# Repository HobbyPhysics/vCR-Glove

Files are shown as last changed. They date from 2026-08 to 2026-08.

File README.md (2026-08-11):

# vCR-Glove
Open-source vibrotactile coordinated reset glove hardware, firmware, and fabrication files

## License

The hardware design files in the `PCB/` and `3D_Printing/` directories are licensed under the CERN Open Hardware Licence Version 2 - Permissive (CERN-OHL-P-2.0). See `LICENSE-HARDWARE.txt`.

The firmware in the `Firmware/` directory is licensed under the MIT License. See `Firmware/LICENSE.txt`.

These licenses permit commercial use of the designs and firmware subject to the terms of the respective licenses. No warranty is provided.

## Project Status

This project is under active development. Design files and documentation may be updated as testing progresses.

## Construction and Technical Experience

This project requires experience with electronic assembly, soldering, PCB fabrication and assembly services, microcontroller programming, and mechanical fabrication.

The documentation and design files are provided to allow technically experienced users to reproduce or modify the project. They are not intended to provide comprehensive instruction in the underlying fabrication and assembly techniques.

Users who do not have experience with these techniques are encouraged to obtain assistance from someone familiar with electronic assembly and fabrication.

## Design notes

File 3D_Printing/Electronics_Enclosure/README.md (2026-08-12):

# Electronics Enclosure

This directory contains the source and fabrication files for the vCR Glove electronics enclosure.

The enclosure houses the printed circuit board, battery, controls, connectors, and related wiring.

## Directory Contents

- `OpenSCAD_Source/` - editable parametric OpenSCAD source files
- `STL/` - rendered STL files for fabrication

See the README files within these directories for additional information.

## Manufacturing

The enclosure parts used in the project were manufactured by JLC3DP using:

- **Process:** SLA
- **Material:** Black resin
- **Supplier:** JLC3DP

The STL files in this repository correspond to the current OpenSCAD source files.

Because SLA dimensions, shrinkage, and warping can vary with resin and process, users employing a different material or manufacturing method should review critical dimensions before fabrication.

## License

These mechanical design files are licensed under CERN-OHL-P-2.0. See `LICENSE-HARDWARE.txt` in the repository root.

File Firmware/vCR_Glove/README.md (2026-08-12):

# vCR Glove Firmware

This directory contains the Arduino firmware for the two vCR Glove electronic units.

The same firmware is used for both the left-hand and right-hand units. A setting near the beginning of the program (IS_LEFT_HAND) identifies which hand is being programmed.

## Requirements

The firmware is intended for the:

- Seeed Studio XIAO nRF52840
- Arduino IDE
- vCR Glove PCB and electronics described in this repository

Install the Arduino IDE and the required board support and libraries before compiling the program.

## Opening the Firmware

Open:

`vCR_Glove.ino`

in the Arduino IDE.

The Arduino IDE should recognize the file as the `vCR_Glove` sketch.

## Selecting the Hand

Before uploading the firmware, locate the following setting near the beginning of the program:

`IS_LEFT_HAND`

Set this value appropriately for the unit being programmed:

- `IS_LEFT_HAND = 1` - left-hand unit
- `IS_LEFT_HAND = 0` - right-hand unit

Both units use otherwise identical firmware.

## Programming the First Unit

1. Turn the vCR Glove unit power switch **OFF**.
2. Connect the unit to the computer using a USB cable.
3. Start the Arduino IDE and open `vCR_Glove.ino`.
4. Set `IS_LEFT_HAND` for the hand being programmed.
5. Select the **Seeed Studio XIAO nRF52840** as the target board.
6. Select the COM port assigned to the connected XIAO.
7. Verify/compile the program.
8. Upload the firmware to the unit.

After a successful upload, disconnect the USB cable.

## Programming the Second Unit

1. Connect the second hand unit to the computer by USB with its power switch **OFF**.
2. Change `IS_LEFT_HAND` to the setting for the second hand.
3. Select the COM port assigned to the second XIAO.
4. Verify/compile the program.
5. Upload the firmware.
6. Disconnect the USB cable.

Both units are now programmed with the same firmware but with their respective left/right hand identifiers.

## Operation

With both units programmed and disconnected from USB:

1. Turn on both units.
2. Press the START button on either unit.
3. The two units establish Bluetooth communication and begin the synchronized stimulation sequence after a short delay.

Only one START button needs to be pressed.

Turning the units off stops operation. After power is restored, stimulation does not begin until a START button is pressed.

## Source Code

Operating parameters and hardware assignments are defined in the Arduino source code. These include the actuator drive parameters, burst timing, channel sequencing, amplitude control, indicator LEDs, amplifier control, and Bluetooth synchronization.

The firmware supplied here corresponds to the vCR Glove hardware documented in this repository.

## Arduino IDE Configuration

The firmware was compiled and tested using the following Arduino board configuration:

* **Board:** Seeed XIAO nRF52840 Sense
* **Board support package:** Seeed nRF52 Boards
* **Tested version:** 1.1.13

Install the `Seeed nRF52 Boards` package using the Arduino IDE Boards Manager and select **Seeed XIAO nRF52840 Sense** as the target board.

The firmware uses:

`#include <bluefruit.h>`

`#include <math.h>`

`#include <nrf.h>`

No separately installed Arduino libraries are required for these includes. In particular, the Bluefruit support used by this firmware is supplied by the `Seeed nRF52 Boards` package.

The similarly named **Seeed nRF52 mbed-enabled Boards** package should not be substituted for the board package specified above.

## Single-frequency mode:

250 Hz on all channels. Closest to the published Tass-style stimulation.

## Multi-frequency mode:
Experimental option using 207.65, 233.08, 277.18, and 311.13 Hz.
Finger order and frequency order are independently shuffled each CR cycle.
This mode has not been evaluated clinically and is not part of the published Tass protocol.

## License

The firmware is licensed under the MIT License. See:

`../LICENSE.txt`

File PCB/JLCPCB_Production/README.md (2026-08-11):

# JLCPCB Production Files

This directory contains the production files used to manufacture and assemble the vCR Glove printed circuit board using JLCPCB.

These files were generated from the KiCad design contained in the adjacent `KiCad_Source` directory.

Detailed ordering instructions are provided in the vCR Glove Project articles on the Hobby Physics blog. The notes below identify several issues that may be encountered when using the JLCPCB ordering system.

## PCB Fabrication

The ZIP file contains the Gerber and drill files required to manufacture the bare PCB.

Upload the ZIP file directly to the JLCPCB PCB ordering system. It is not necessary to extract the individual Gerber and drill files before uploading.

## PCB Assembly

The two CSV files are used for JLCPCB PCB assembly:

- **BOM (Bill of Materials)** - identifies the components and their reference designators.
- **Top Position / Pick-and-Place file** - specifies the location and orientation of the components installed on the top side of the PCB.

These files are uploaded during the PCB assembly portion of the JLCPCB ordering process.

## Important Assembly Checks

The JLCPCB assembly configuration and component placement should be carefully reviewed before placing an order. The production files provide the design information, but some selections and corrections may be required in the JLCPCB ordering interface.

### Component Availability

JLCPCB/LCSC component availability, pricing, and minimum order quantities can change.

A component specified in the BOM may become unavailable or may require a different minimum quantity. The JLCPCB system may report an error or suggest substitute components.

Any substitute should be checked for electrical specifications, package, footprint, and pinout before accepting it.

### DNP Components

Some components in the KiCad schematic are designated **DNP (Do Not Populate)** and are marked with a red X.

These components are intentionally not installed. JLCPCB may display warnings or comments associated with these unpopulated locations. These should not be interpreted as missing components that must necessarily be added.

The intended populated configuration should be compared with the schematic before responding to DNP-related warnings.

### Component Orientation and Position

Do not assume that all components shown in the JLCPCB assembly viewer have the correct orientation or exact position.

Differences between the KiCad placement data and the JLCPCB assembly system can result in some components appearing rotated or displaced in the JLCPCB viewer.

In the board used for this project, particular attention should be paid to:

- **JST connectors** - some may require rotation by 90 or 180 degrees and adjustment of their position so that they align correctly with the PCB through holes.
- **Electrolytic capacitor** - the capacitor may require a 180-degree rotation and position adjustment. Polarity must be checked carefully.

The JLCPCB assembly editing tools can be used during the ordering process to correct component rotation and position.

## Before Ordering

Before approving PCB assembly:

1. Review all BOM component selections and resolve unavailable components carefully.
2. Confirm that DNP components remain unpopulated.
3. Inspect the orientation and position of every component in the JLCPCB assembly viewer.
4. Pay particular attention to connectors and polarized components.
5. Compare the JLCPCB assembly preview with the KiCad PCB layout, schematic, and 3D view.

Do not approve the assembly solely because the BOM and placement files were accepted without errors.

## Design Version

These production files correspond to the PCB version documented in this repository. JLCPCB component inventory and its ordering interface may change over time.

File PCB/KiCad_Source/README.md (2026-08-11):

# KiCad Source Files
# KiCad Source Files

This directory contains the editable KiCad source files for the vCR Glove printed circuit board.

The project was created using KiCad. To open the complete project, start KiCad and open the `.kicad_pro` project file. The schematic and PCB layout can then be opened from the KiCad Project Manager.

## Files

- `.kicad_pro` - KiCad project file
- `.kicad_sch` - schematics
- `.kicad_pcb` - PCB layout

## Schematic DNP Markings

Some components in the schematic are marked with a red X. These components have been designated **DNP (Do Not Populate)** in KiCad.

The components are intentionally retained in the schematic but are not installed on the manufactured PCB. The red X is therefore not an error indication. It provides a visual record of optional or unused components and identifies the configuration used for production.

## Viewing the PCB

Open the `.kicad_pcb` file from the KiCad Project Manager to view the PCB layout.

KiCad can also display a three-dimensional representation of the assembled PCB. With the PCB Editor open, select:

**View → 3D Viewer**

The 3D Viewer can be rotated and zoomed to inspect the component placement and overall board assembly.

## Manufacturing Files

The files used to order the PCB and assembled board are provided separately in:

`../JLCPCB_Production/`

Those production files should be used for reproducing the manufactured board. The files in this directory are provided for viewing or modifying the design.

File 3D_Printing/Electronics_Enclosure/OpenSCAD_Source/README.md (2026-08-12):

# Electronics Enclosure OpenSCAD Source

This directory contains the editable OpenSCAD source file for the vCR Glove electronics enclosure.

A single OpenSCAD file defines both printable components of the enclosure and also provides assembled and exploded views for inspection.

## Selecting the Output

The variable `output_part` near the beginning of the OpenSCAD file selects what is displayed:

- `output_part = "box";` - enclosure bottom
- `output_part = "top";` - enclosure top (lid)
- `output_part = "assembly";` - assembled view for inspection
- `output_part = "exploded";` - exploded view for inspection

The `assembly` and `exploded` options are provided for visualization and are not intended to generate manufacturing STL files.

## Generating the STL Files

Two STL files are required for fabrication.

### Enclosure Bottom

Set:

`output_part = "box";`

Press **F6** to render the model, inspect it, and then select:

**File → Export → Export as STL**

Save the result using the `_bottom.stl` filename.

### Enclosure Top

Set:

`output_part = "top";`

Press **F6** to render the model, inspect it, and then select:

**File → Export → Export as STL**

Save the result using the `_top.stl` filename.

The resulting STL files are provided in:

`../STL/`

## Viewing the Complete Enclosure

For an assembled view, set:

`output_part = "assembly";`

For a separated view showing the relationship between the components, set:

`output_part = "exploded";`

These modes are useful for inspecting the enclosure design without generating separate manufacturing parts.

## Parametric Design

The enclosure is designed parametrically. Important dimensions are defined near the beginning of the OpenSCAD source file.

If dimensions are changed, both the top and bottom should be reviewed and new STL files generated as necessary.

## Manufacturing

The enclosure used in the project was manufactured by JLC3DP using:

- **Process:** SLA
- **Material:** Black resin

Manufacturing tolerances, shrinkage, and warping can vary with material and process. Critical dimensions should therefore be reviewed if a different manufacturing process or material is used.

## License

The OpenSCAD source file is a hardware design file licensed under CERN-OHL-P-2.0. See `LICENSE-HARDWARE.txt` in the repository root.

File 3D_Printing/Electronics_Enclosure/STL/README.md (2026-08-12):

# Electronics Enclosure STL Files

This directory contains the STL files used to manufacture the electronics enclosure components.

The STL files were generated from the corresponding OpenSCAD source files in:

`../OpenSCAD_Source/`

## Generating the STL Files

Open the corresponding `.scad` file in OpenSCAD, perform an **F6 Render**, and then select:

**File → Export → Export as STL**

## Manufacturing

The enclosure parts used in the project were manufactured by JLC3DP using:

- **Process:** SLA
- **Material:** Black resin

Before ordering, inspect the uploaded model in the JLC3DP viewer and confirm the part dimensions and geometry.

## Source Files

The OpenSCAD files in `../OpenSCAD_Source/` are the authoritative editable source.

If dimensions are changed, regenerate the corresponding STL rather than editing the STL directly.

## License

These STL files are derived from hardware designs licensed under CERN-OHL-P-2.0. See `LICENSE-HARDWARE.txt` in the repository root.elec enclosure stl

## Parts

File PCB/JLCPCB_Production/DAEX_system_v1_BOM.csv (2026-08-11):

Comment | Designator | Footprint | JLCPCB Part #
PAM8403DR-H | U1,U2 | SOIC-16_3.9x9.9mm_P1.27mm | C17337
DAEX_CH1 | J9, J11, J12, J10, J1 | JST_PH_S2B-PH-K_1x02_P2.00mm_Horizontal | C173752
10K | R19,R18,R12,R11 | R_0805_2012Metric | C176201
3.3k | R17,R16,R15,R14,R6,R9,R10,R7 | R_0805_2012Metric | C26010
100K | R13,R8 | R_0805_2012Metric | C22356675
1k | R1 | R_0805_2012Metric | C22356679
2.2k | R3,R5,R4,R2 | R_0805_2012Metric | C17520
1uF | C26,C23,C20,C12,C15,C9 | C_0805_2012Metric | C28323
470nF | C25,C24,C13,C14 | C_0805_2012Metric | C1778
22nF | C22,C21,C6,C17,C11,C7,C18,C10 | C_0805_2012Metric | C1729
22nF | C5, C16 | C_1206_3216Metric | C1856
100nF | C19,C2,C8,C4 | C_0805_2012Metric | C49678
10uF | C3 | C_0805_2012Metric | C15850
220uF | C1 | CP_Elec_6.3x5.4 | C3345

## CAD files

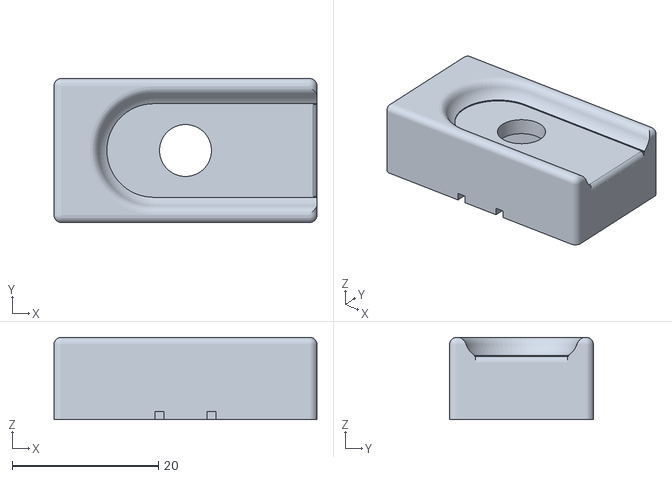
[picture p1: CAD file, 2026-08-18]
3D_Printing/DAEX_Housing/STL/DAEX_upper_housing.stl
36.0 x 19.7 x 11.3

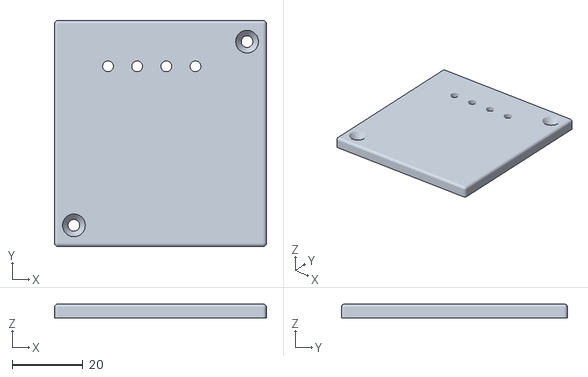
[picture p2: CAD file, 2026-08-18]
3D_Printing/Electronics_Enclosure/STL/vCR_glove_enclosure_top.stl
60.0 x 64.0 x 4.00

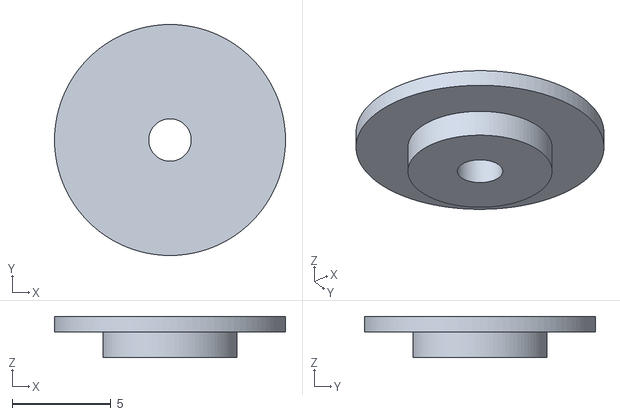
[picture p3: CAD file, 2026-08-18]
3D_Printing/DAEX_Housing/STL/DAEX_tapper.stl
11.7 x 11.7 x 2.10

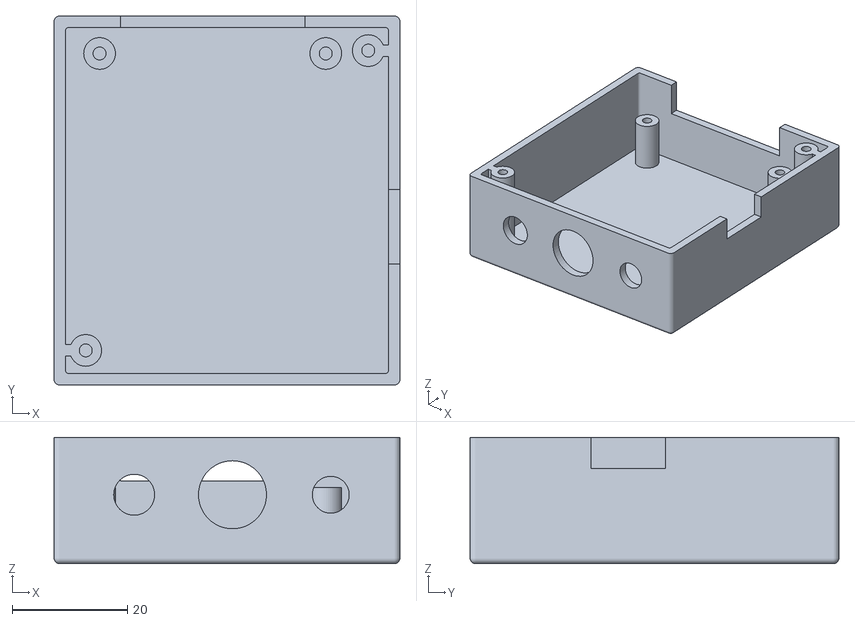
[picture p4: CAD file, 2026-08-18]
3D_Printing/Electronics_Enclosure/STL/vCR_glove_enclosure_bottom.stl
60.0 x 64.0 x 21.9

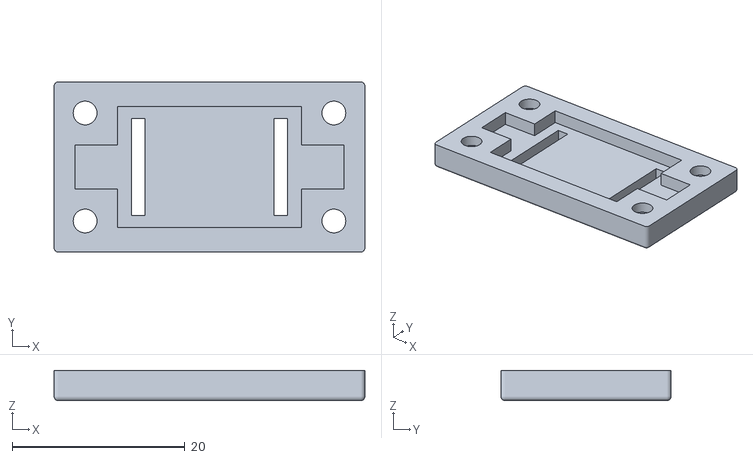
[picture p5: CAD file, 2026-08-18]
3D_Printing/DAEX_Housing/STL/DAEX_lower_plate.stl
36.0 x 19.7 x 3.50

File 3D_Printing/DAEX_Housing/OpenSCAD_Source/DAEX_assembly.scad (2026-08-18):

/*
DAEX_assembly.scad

Assembly visualization and interference-checking file for the DAEX-9-4SM
vibrotactile actuator assembly.

Required files in the same folder:
    DAEX_dimensions.scad
    DAEX_upper_housing.scad
    DAEX_lower_plate.scad
    DAEX_tapper.scad

This file does NOT reproduce the part geometry. It imports the named modules
from the three part files, positions them, and provides visualization tools.

OpenSCAD command summary
------------------------

include <file.scad>
    Reads variables, functions, modules, and top-level geometry from a file.
    Here it is used for the common dimensional specification.

use <file.scad>
    Imports modules and functions from a file, but ignores that file's
    top-level rendered objects. This is ideal for assembly files because the
    part scripts may render themselves when opened directly, while this file
    calls only their named modules.

translate([x, y, z])
    Moves the following object by the specified X, Y, and Z distances.
    Example:
        translate([0, 0, 5])
            DAEX_tapper();
    moves the tapper upward by 5 mm.

color([r, g, b, a])
    Changes the display color of the following object.
    r, g, and b range from 0 to 1.
    Optional a is opacity: 1 = opaque, 0 = invisible.
    Example:
        color([0.2, 0.6, 0.9, 0.4])
    displays a translucent blue object.

intersection() {
    object_A();
    object_B();
}
    Keeps only volume occupied by BOTH objects. In interference mode, any
    visible result represents physical overlap between two nominally separate
    parts.

difference() {
    object_A();
    object_B();
}
    Keeps object A after subtracting object B.

intersection() used with a large cube
    provides a section view: only the portion of the assembly inside the cube
    remains visible.
*/


// ============================================================================
// Imported dimensions and part modules
// ============================================================================

include <DAEX_dimensions.scad>

use <DAEX_upper_housing.scad>
use <DAEX_lower_plate.scad>
use <DAEX_tapper.scad>


// ============================================================================
// Main controls
// ============================================================================

// Select one:
// "assembled"
// "exploded"
// "transparent"
// "section_xz"
// "section_yz"
// "interference_all"
// "interference_upper_plate"
// "interference_upper_tapper"
// "interference_plate_tapper"
view_mode = "exploded";


// Z separation controls, in millimeters.
//
// These are visualization settings rather than manufactured dimensions, so
// they belong in this assembly file rather than DAEX_dimensions.scad.
//
// Set all three to zero for the nominal assembled positions.
// Positive values move a part upward; negative values move it downward.
upper_z_separation = 0;
plate_z_separation = 0;
tapper_z_separation = -1;

// Convenient default exploded-view distances. These are used only when
// view_mode = "exploded".
exploded_upper_gap = 8;
exploded_plate_gap = -8;
exploded_tapper_gap = -2;


// Section-plane controls.
//
// For section_xz, Y material greater than section_y is removed.
// section_y = 0 gives a center XZ half-section.
//
// For section_yz, X material greater than section_x is removed.
// section_x = 0 gives a center YZ half-section.
section_x = 0;
section_y = 0;

// Size of the clipping cube used for section views.
section_box_size = 120;


// Display colors: [red, green, blue, opacity]
upper_color = [0.78, 0.82, 0.88, 1.00];
plate_color = [0.30, 0.34, 0.40, 1.00];
tapper_color = [0.90, 0.45, 0.15, 1.00];

transparent_upper_color = [0.78, 0.82, 0.88, 0.35];
transparent_plate_color = [0.30, 0.34, 0.40, 0.35];
transparent_tapper_color = [0.90, 0.45, 0.15, 0.85];

interference_color = [1.00, 0.00, 0.00, 1.00];


// ============================================================================
// Nominal assembly placement
// ============================================================================

// The upper housing module is centered on its own origin.
upper_nominal_z = 0;

// The lower plate top face mates to the upper housing bottom face.
//
// Upper bottom face: -housing_z/2
// Plate top face:    plate_center_z + plate_z/2
//
// Therefore:
// plate_center_z = -housing_z/2 - plate_z/2
plate_nominal_z = -(housing_z + plate_z)/2;


// Nominal tapper placement
// -------------------------
//
// The tapper's broad middle cylinder is assumed to lie below the housing's
// center-hole roof, with the top of the middle cylinder aligned to the upper
// surface of the main DAEX cavity:
//
// cavity_roof_z = -housing_z/2 + cavity_depth
//
// In DAEX_tapper, the top face of the broad cylinder is:
// tapper_mid_center_z + tapper_mid_z/2
//
// The expression below aligns those two surfaces. This is a useful nominal
// assembly location, but tapper_z_separation can be adjusted to represent
// adhesive thickness, DAEX suspension position, or alternate tapper heights.
cavity_roof_z = -housing_z/2 + cavity_depth;

tapper_mid_top_local_z =
    tapper_mid_center_z + tapper_mid_z/2;

tapper_nominal_z =
    cavity_roof_z - tapper_mid_top_local_z;


// Final positions after applying user-controlled visual separations.
upper_position_z =
    upper_nominal_z + upper_z_separation;

plate_position_z =
    plate_nominal_z + plate_z_separation;

tapper_position_z =
    tapper_nominal_z + tapper_z_separation;


// ============================================================================
// Positioned part modules
// ============================================================================

module positioned_upper() {
    translate([0, 0, upper_position_z])
        DAEX_upper_housing();
}

module positioned_plate() {
    translate([0, 0, plate_position_z])
        DAEX_lower_plate();
}

module positioned_tapper() {
    translate([0, 0, tapper_position_z])
        DAEX_tapper();
}


// Exploded positions use the nominal positions plus dedicated exploded gaps.
module exploded_upper() {
    translate([0, 0, upper_nominal_z + exploded_upper_gap])
        DAEX_upper_housing();
}

module exploded_plate() {
    translate([0, 0, plate_nominal_z + exploded_plate_gap])
        DAEX_lower_plate();
}

module exploded_tapper() {
    translate([0, 0, tapper_nominal_z + exploded_tapper_gap])
        DAEX_tapper();
}


// ============================================================================
// Assembly display modules
// ============================================================================

module assembled_view(transparent=false) {
    if (transparent) {
        color(transparent_upper_color)
            positioned_upper();

        color(transparent_plate_color)
            positioned_plate();

        color(transparent_tapper_color)
            positioned_tapper();
    } else {
        color(upper_color)
            positioned_upper();

        color(plate_color)
            positioned_plate();

        color(tapper_color)
            positioned_tapper();
    }
}


module exploded_view() {
    color(upper_color)
        exploded_upper();

    color(plate_color)
        exploded_plate();

    color(tapper_color)
        exploded_tapper();
}


// A geometry-only assembly without colors.
// This is used by section and other Boolean operations.
module complete_assembly_geometry() {
    positioned_upper();
    positioned_plate();
    positioned_tapper();
}


// ============================================================================
// Section views
// ============================================================================

module section_xz_view() {
    // Keeps the half of the assembly at Y <= section_y.
    //
    // intersection() returns only the volume common to:
    //   1. the complete assembly
    //   2. the large clipping cube
    //
    // Because the cube ends at section_y, the result is an XZ cutaway.
    intersection() {
        complete_assembly_geometry();

        translate([
            -section_box_size/2,
            section_y - section_box_size,
            -section_box_size/2
        ])
            cube([
                section_box_size,
                section_box_size,
                section_box_size
            ]);
    }
}


module section_yz_view() {
    // Keeps the half of the assembly at X <= section_x.
    // The clipping cube creates a YZ cutaway.
    intersection() {
        complete_assembly_geometry();

        translate([
            section_x - section_box_size,
            -section_box_size/2,
            -section_box_size/2
        ])
            cube([
                section_box_size,
                section_box_size,
                section_box_size
            ]);
    }
}


// ============================================================================
// Interference checks
// ============================================================================
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

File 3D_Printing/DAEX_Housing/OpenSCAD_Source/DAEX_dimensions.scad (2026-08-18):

/*
DAEX_dimensions.scad

Shared dimensional parameters for the DAEX-9-4SM actuator assembly.

Units: millimeters

Coordinate convention used by the housing and lower plate:
X = along finger / actuator length
Y = across finger / actuator width
Z = thickness
Housing origin = center of upper housing
Plate origin   = center of lower plate
Top = +Z
Bottom = -Z

This file contains:
- common direct dimensions
- upper-housing dimensions
- lower-plate dimensions
- screw-adjustable tapper dimensions
- common derived dimensions and feature-center coordinates

It intentionally contains no rendered geometry.
*/

// ============================================================================
// Rendering / Boolean-control values
// ============================================================================

upper_fn = 72;
lower_fn = 72;
tapper_fn = 96;

eps = 0.04;
small_extension = 0.08;


// ============================================================================
// Common assembly envelope
// ============================================================================

housing_x = 36.0;
housing_y = 19.7;
housing_z = 11.25;

plate_x = housing_x;
plate_y = housing_y;
plate_z = 3.5;


// ============================================================================
// DAEX actuator and central cavity
// ============================================================================

DAEX_x = 31.0;

cavity_x = 21.3;
cavity_y = 14.0;

// Upper-housing cavity depth measured upward from the housing bottom
cavity_depth = 6.25;

// Lower-plate top pocket depth measured downward from the plate top
cavity_z = 1.8;


// ============================================================================
// Common exterior end- and side-wall dimensions
// ============================================================================

x_wall_width = (housing_x - DAEX_x)/2;
y_wall_width = (housing_y - cavity_y)/2;


// ============================================================================
// Screw system shared by upper housing and lower plate
// ============================================================================

counterbore_d = 5.2;
counterbore_depth = 2.1;

screw_head_offset = 1.0;
screw_offset = counterbore_d/2 + screw_head_offset;

// Four screw/hole center magnitudes from the assembly origin
screw_center_x = housing_x/2 - screw_offset;
screw_center_y = housing_y/2 - screw_offset;

// Upper housing pilot/tap holes
tap_hole_d = 2.25;
tap_hole_depth = 6.0;

// Lower plate clearance holes
clearance_hole_d = 2.75;


// ============================================================================
// Upper-housing exterior fillets
// ============================================================================

comfort_r = 1.0;
comfort_steps = 12;


// ============================================================================
// Upper-housing DAEX ledges
// ============================================================================

ledge_x = 1.65;
ledge_y = 11.4;
ledge_depth = 2.7;

ledge_center_x = cavity_x/2 + ledge_x/2;


// ============================================================================
// Shared contact-cavity geometry
// ============================================================================

contact_cavity_y = 5.1;

// Upper-housing contact-cavity depth
contact_cavity_depth = 2.7;

// Lower-plate contact-cavity depth
contact_cavity_z = cavity_z;

// Contact-cavity X length is the space from the ledge to the inner face
// of the closed +/-X end wall.
contact_cavity_x =
    housing_x/2 -
    cavity_x/2 -
    ledge_x -
    x_wall_width;

// Upper housing: cavity center lies beyond the ledge
upper_contact_cavity_center_x =
    cavity_x/2 +
    ledge_x +
    contact_cavity_x/2;

// Lower plate: cavity runs directly from the central pocket edge
// to the inner face of the closed +/-X end wall.
lower_contact_cavity_x =
    (plate_x - cavity_x)/2 -
    x_wall_width;

lower_contact_cavity_center_x =
    cavity_x/2 +
    lower_contact_cavity_x/2;

contact_cavity_center_y = 0;



// ============================================================================
// Perimeter wire-routing L steps in upper housing
// ============================================================================

// Wire diameter is also the nominal L-step width and depth.
wire_d = 1.10;
wire_step_depth = 1.3;

// Radius produced by the 3/16-inch end mill used on the machined prototype.
// 3/16 in diameter = 4.7625 mm, therefore radius = 2.38125 mm.
wire_step_corner_r = 2.38125;
wire_step_corner_steps = 16;

// Extend the L-step cutter slightly into the contact cavity at the 3rd/4th
// vertices so coincident faces do not leave a zero-thickness Boolean wall.
wire_step_contact_overlap = small_extension;

// Extend vertices 5 and 6 into the ledge subtraction so the two cuts
// overlap and cannot leave a thin Boolean wall.
wire_step_ledge_overlap = small_extension;

// Base six XY vertices for the -X,-Y L-shaped step.
// The geometry script replaces the outer corner (vertex 1) with a quarter
// circle of wire_step_corner_r.  The +X,-Y step is mirrored about X=0.
wire_step_left_points = [
    [-cavity_x/2,                        -cavity_y/2],
    [-cavity_x/2 - ledge_x - wire_d,    -cavity_y/2],
    [-cavity_x/2 - ledge_x - wire_d,
        -contact_cavity_y/2 + wire_step_contact_overlap],
    [-cavity_x/2 - ledge_x,
        -contact_cavity_y/2 + wire_step_contact_overlap],
    [-cavity_x/2 - ledge_x,
        -ledge_y/2 + wire_step_ledge_overlap],
    [-cavity_x/2,
        -ledge_y/2 + wire_step_ledge_overlap]
];

// Derived center of the rounded outer corner for the -X,-Y step.
// The radius is tangent to the bottom horizontal edge and outer vertical edge.
wire_step_left_corner_center_x =
    wire_step_left_points[1][0] + wire_step_corner_r;

wire_step_left_corner_center_y =
    wire_step_left_points[1][1] + wire_step_corner_r;



// ============================================================================
// Upper-housing rectangular wire exit slots
// ============================================================================

// These replace the former matching semicylindrical clamp grooves.
// Strain relief is provided by the perimeter L steps and DAEX frame; the
// rectangular slots simply capture and guide the wires out through the -Y wall.
wire_groove_width = 1.27;
wire_groove_depth = 1.10;
wire_groove_x = 3.56;

wire_groove_center_y =
    -(cavity_y/2 + y_wall_width/2);

// Slot length traverses the full -Y wall, with a small overcut at both ends
// so no thin Boolean skin remains at the cavity or outside surface.
wire_groove_length = y_wall_width + 2*small_extension;


// ============================================================================
// Upper-housing center hole
// ============================================================================

center_hole_d = 7.1;


// ============================================================================
// Upper-housing finger groove
// ============================================================================

finger_groove_x = 27.6;
finger_groove_y = 15.5;
finger_groove_depth = 2.5;
finger_groove_x_offset = 1.7;

finger_groove_plan_radius = 8.0;
finger_groove_side_radius = 3.0;
finger_groove_fillet_radius = 1.0;
finger_groove_steps = 40;

groove_open_end_beyond_housing = 0.60;
finger_groove_open_x_max =
    housing_x/2 + groove_open_end_beyond_housing;


// ============================================================================
// Lower-plate exterior fillets
// ============================================================================

plate_fillet_radius = 0.5;
plate_fillet_steps = 10;


// ============================================================================
// Lower-plate vent slots
// ============================================================================

vent_x = 1.6;
vent_y = 11.2;
vent_center_x = cavity_x/2 - 3*vent_x/2;


// ============================================================================
// Screw-adjustable tapper
// ============================================================================

// Broad upper cylinder bonded to / carried by the DAEX moving element
tapper_mid_d = 11.7;
tapper_mid_z = 0.8;

// Lower locating cylinder
tapper_bottom_d = 6.8;
tapper_bottom_z = 1.3;

// Center through-hole, subsequently tapped for an M2.5 adjustment screw
tapper_hole_d = 2.15;

tapper_total_z =
    tapper_mid_z +
    tapper_bottom_z;

// Tapper-cylinder center Z coordinates when the tapper origin is at the
// center of the complete two-cylinder stack.
tapper_bottom_center_z =
    -tapper_total_z/2 +
    tapper_bottom_z/2;

tapper_mid_center_z =
    -tapper_total_z/2 +
    tapper_bottom_z +
    tapper_mid_z/2;


// ============================================================================
// Assembly-level derived dimensions
// ============================================================================

assembled_body_z = housing_z + plate_z;
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

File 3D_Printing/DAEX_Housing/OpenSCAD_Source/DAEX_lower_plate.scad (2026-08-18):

/*
DAEX_lower_plate.scad

Lower plate for the DAEX-9-4SM actuator housing.

All fixed and shared derived dimensions are supplied by:
    DAEX_dimensions.scad

This file contains only the OpenSCAD geometry processes used to construct
the lower plate.

Coordinate convention:
X = along finger / actuator length
Y = across finger / actuator width
Z = thickness
Top = +Z mating side
Bottom = -Z screw-head and PSA side
Origin = center of plate
*/

include <DAEX_dimensions.scad>

$fn = lower_fn;


// ---------- Utility geometry ----------

module rounded_rect_2d(l, w, r) {
    rr = min(r, l/2 - 0.001, w/2 - 0.001);
    hull() {
        for (sx = [-1, 1])
            for (sy = [-1, 1])
                translate([sx*(l/2 - rr), sy*(w/2 - rr)])
                    circle(r = rr);
    }
}

// Positive plate body with vertical outside corner fillets and bottom roundover.
// Top perimeter edge is intentionally left square for mating to upper housing.
module exterior_body_bottom_and_vertical_filleted(l, w, h, r, steps=10) {
    z_bot = -h/2;

    // Main upper portion: vertical outside corner radius only.
    translate([0, 0, z_bot + r - eps])
        linear_extrude(height = h - r + eps)
            rounded_rect_2d(l, w, r);

    // Bottom roundover, approximated by hulling thin rounded-rectangle slices.
    for (i = [0:steps-1]) {
        hull() {
            exterior_bottom_slice(l, w, h, r, steps, i);
            exterior_bottom_slice(l, w, h, r, steps, i+1);
        }
    }
}

module exterior_bottom_slice(l, w, h, r, steps, i) {
    t = i / steps;
    dz = r * t;
    inset = r - sqrt(max(0, r*r - dz*dz));
    z = -h/2 + r - dz;

    translate([0, 0, z])
        linear_extrude(height = eps)
            rounded_rect_2d(l - 2*inset, w - 2*inset, max(0.001, r - inset));
}


// ---------- Cut features ----------

module top_cavity_pocket_cut() {
    translate([0, 0, plate_z/2 - cavity_z/2 + eps])
        cube([cavity_x, cavity_y, cavity_z + 2*eps], center=true);
}

module top_contact_cavity_cuts() {
    for (sx = [-1, 1]) {
        translate([
            sx*lower_contact_cavity_center_x,
            contact_cavity_center_y,
            plate_z/2 - contact_cavity_z/2 + eps
        ])
            cube([
                lower_contact_cavity_x + 2*small_extension,
                contact_cavity_y,
                contact_cavity_z + 2*eps
            ], center=true);
    }
}


module vent_slot_cuts() {
    for (sx = [-1, 1]) {
        translate([sx*vent_center_x, 0, 0])
            cube([vent_x, vent_y, plate_z + 2*eps], center=true);
    }
}

module clearance_hole_cuts() {
    for (sx = [-1, 1])
        for (sy = [-1, 1])
            translate([
                sx*screw_center_x,
                sy*screw_center_y,
                -plate_z/2 - eps
            ])
                cylinder(d = clearance_hole_d, h = plate_z + 2*eps);
}

module counterbore_cuts() {
    for (sx = [-1, 1])
        for (sy = [-1, 1])
            translate([
                sx*screw_center_x,
                sy*screw_center_y,
                -plate_z/2 - eps
            ])
                cylinder(d = counterbore_d, h = counterbore_depth + eps);
}


// ---------- Final part ----------

module DAEX_lower_plate() {
    difference() {
        exterior_body_bottom_and_vertical_filleted(
            plate_x,
            plate_y,
            plate_z,
            plate_fillet_radius,
            plate_fillet_steps
        );

        // Top mating features
        top_cavity_pocket_cut();
        top_contact_cavity_cuts();

        // Through features
        vent_slot_cuts();
        clearance_hole_cuts();

        // Bottom screw-head counterbores
        counterbore_cuts();
    }
}

// Render this part when the file is opened directly.
DAEX_lower_plate();

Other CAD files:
3D_Printing/DAEX_Housing/OpenSCAD_Source/DAEX_tapper.scad
3D_Printing/DAEX_Housing/OpenSCAD_Source/DAEX_upper_housing.scad
3D_Printing/Electronics_Enclosure/OpenSCAD_Source/vCR_glove_enclosure.scad

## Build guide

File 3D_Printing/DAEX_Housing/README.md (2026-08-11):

# DAEX Housing

This directory contains the source and fabrication files for the finger-mounted housing used with the Dayton Audio DAEX-9-4SM exciter in the vCR Glove.

The housing consists of three 3D-printed parts:

- Upper housing
- Lower plate
- Tapper

The DAEX-9-4SM is mounted within the housing, and the tapper provides the mechanical contact between the moving portion of the actuator and the finger.

## Directory Contents

- `OpenSCAD_Source/` - editable parametric OpenSCAD source files and an assembly model for viewing the completed housing
- `STL/` - rendered STL files for manufacturing the three individual housing components

See the README files within these directories for additional information.

## Manufacturing

The parts used in the project were manufactured by JLC3DP using:

- **Process:** Multi Jet Fusion (MJF)
- **Material:** Nylon
- **Color:** Black

The STL files in this repository correspond to the current OpenSCAD source files.

Manufacturing tolerances can vary with process, material, and supplier. Users employing a different manufacturing process or material should review critical dimensions before fabrication.

## License

These mechanical design files are licensed under CERN-OHL-P-2.0. See `LICENSE-HARDWARE.txt` in the repository root.

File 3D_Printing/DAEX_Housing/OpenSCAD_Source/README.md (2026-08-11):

# OpenSCAD Source Files

This directory contains the editable OpenSCAD source files for the 3D-printed mechanical components used in the vCR Glove project.

The OpenSCAD files are the authoritative source for the current mechanical design. STL files should be generated from these sources after the design parameters have been reviewed and, if necessary, adjusted for the selected manufacturing process.

## Opening the Files

Install OpenSCAD and open the desired `.scad` file.

After opening a file:

1. Review the adjustable parameters near the beginning of the source file.
2. Press **F5** for Preview.
3. Press **F6** for Render.
4. Rotate and inspect the model to verify the geometry.
5. After rendering, export the model using:

**File → Export → Export as STL**

## Parametric Design

The mechanical parts were designed parametrically. Important dimensions are defined near the beginning of each OpenSCAD file so that the geometry can be adjusted without rewriting the model.

When modifying dimensions, render and inspect the model before exporting an STL.

## Manufacturing

The project parts were produced using JLC3DP.

The final STL files used for manufacturing are provided separately in:

`../STL/`

Because 3D-printing tolerances and material behavior vary by process and supplier, dimensional adjustments may be required for a different printer, material, or fabrication method.

## License

The OpenSCAD source files in this directory are hardware design files and are licensed under CERN-OHL-P-2.0. See the repository root file:

`LICENSE-HARDWARE.txt`

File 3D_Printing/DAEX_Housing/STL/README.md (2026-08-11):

# DAEX Housing STL Files

This directory contains the STL files used to manufacture the three components of the DAEX actuator housing:

- Upper housing
- Lower plate
- Tapper

The STL files were generated from the corresponding OpenSCAD source files in:

`../OpenSCAD_Source/`

## Generating the STL Files

The supplied STL files were generated by opening each printable component in OpenSCAD, performing an **F6 Render**, and then selecting:

**File → Export → Export as STL**

The assembly and dimensions OpenSCAD files are not intended to generate manufacturing STL files.

## Manufacturing

The parts used in the project were manufactured by JLC3DP using:

- **Process:** Multi Jet Fusion (MJF)
- **Material:** Nylon
- **Color:** Black

The STL files can be uploaded to the JLC3DP ordering system for fabrication.

Before ordering, the uploaded models should be inspected in the JLC3DP viewer to confirm the geometry and dimensions.

## Source Files

The OpenSCAD files in `../OpenSCAD_Source/` are the authoritative editable source for these parts.

If a mechanical dimension is changed in the OpenSCAD source, the affected STL file should be rendered and exported again rather than modifying the STL directly.

## License

These STL files are derived from hardware designs licensed under CERN-OHL-P-2.0. See `LICENSE-HARDWARE.txt` in the repository root.

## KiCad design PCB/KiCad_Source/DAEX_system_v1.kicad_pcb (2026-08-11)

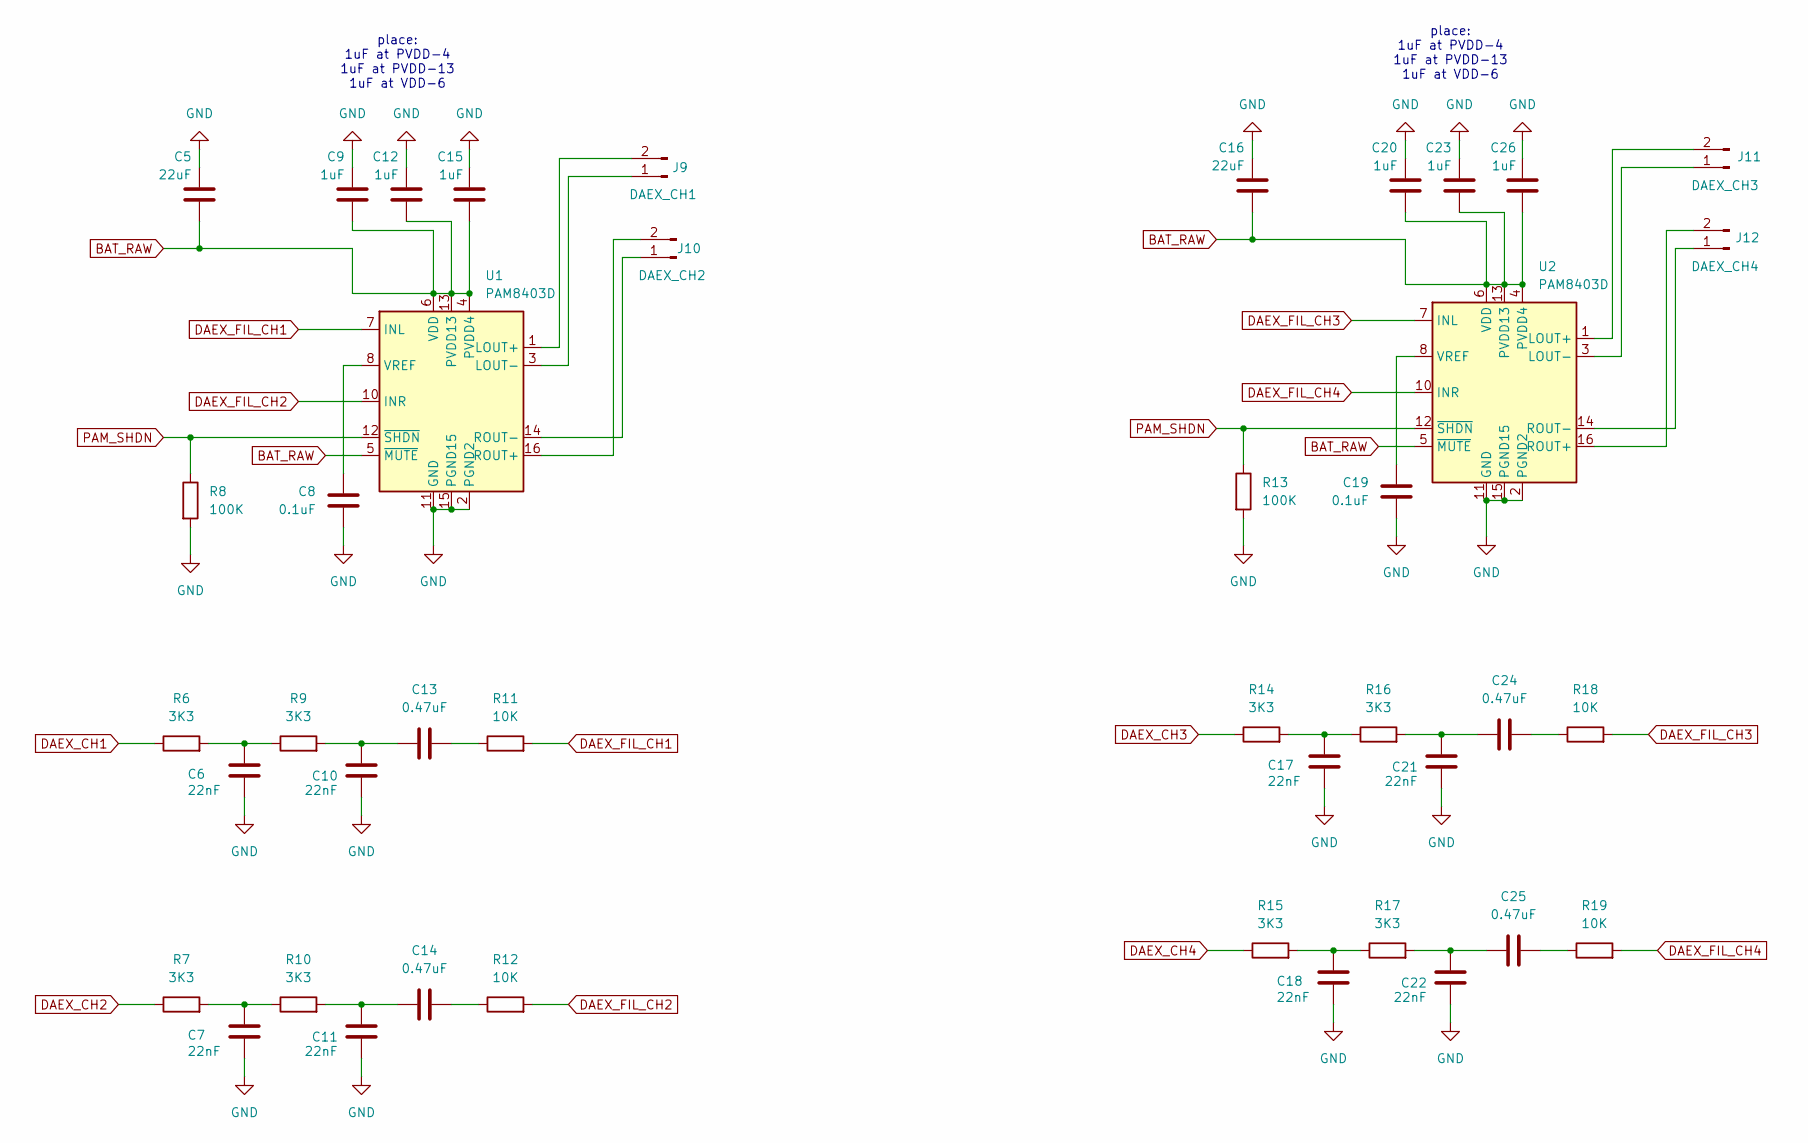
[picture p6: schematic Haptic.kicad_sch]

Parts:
C5, C16: 22uF; C_1206_3216Metric
C6, C7, C10, C11, C17, C18, C21, C22: 22nF; C_0805_2012Metric
C8, C19: 0.1uF; C_0805_2012Metric
C9, C12, C15, C20, C23, C26: 1uF; C_0805_2012Metric
C13, C14, C24, C25: 0.47uF; C_0805_2012Metric
J9: DAEX_CH1; JST_PH_S2B-PH-K_1x02_P2.00mm_Horizontal
J10: DAEX_CH2; JST_PH_S2B-PH-K_1x02_P2.00mm_Horizontal
J11: DAEX_CH3; JST_PH_S2B-PH-K_1x02_P2.00mm_Horizontal
J12: DAEX_CH4; JST_PH_S2B-PH-K_1x02_P2.00mm_Horizontal
R6, R7, R9, R10, R14, R15, R16, R17: 3K3; R_0805_2012Metric
R8, R13: 100K; R_0805_2012Metric
R11, R12, R18, R19: 10K; R_0805_2012Metric
U1, U2: PAM8403D; SOIC-16_3.9x9.9mm_P1.27mm

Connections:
BAT_RAW: C5.1, C9.1, C12.1, C15.1, C16.1, C20.1, C23.1, C26.1, U1.4 (PVDD4), U1.5 (~MUTE), U1.6 (VDD), U1.13 (PVDD13), U2.4 (PVDD4), U2.5 (~MUTE), U2.6 (VDD), U2.13 (PVDD13); also elsewhere on the board
DAEX_CH1: R6.1; also elsewhere on the board
DAEX_CH2: R7.1; also elsewhere on the board
DAEX_CH3: R14.1; also elsewhere on the board
DAEX_CH4: R15.1; also elsewhere on the board
DAEX_FIL_CH1: R11.2, U1.7 (INL)
DAEX_FIL_CH2: R12.2, U1.10 (INR)
DAEX_FIL_CH3: R18.2, U2.7 (INL)
DAEX_FIL_CH4: R19.2, U2.10 (INR)
GND: C5.2, C6.1, C7.1, C8.1, C9.2, C10.1, C11.1, C12.2, C15.2, C16.2, C17.1, C18.1, C19.1, C20.2, C21.1, C22.1, C23.2, C26.2, R8.2, R13.2, U1.2 (PGND2), U1.11 (GND), U1.15 (PGND15), U2.2 (PGND2), U2.11 (GND), U2.15 (PGND15); also elsewhere on the board
unnamed: C6.2, R6.2, R9.1
unnamed: C7.2, R7.2, R10.1
unnamed: C10.2, C13.1, R9.2
unnamed: C11.2, C14.1, R10.2
unnamed: C13.2, R11.1
unnamed: C14.2, R12.1
unnamed: C17.2, R14.2, R16.1
unnamed: C18.2, R15.2, R17.1
unnamed: C21.2, C24.1, R16.2
unnamed: C22.2, C25.1, R17.2
unnamed: C24.2, R18.1
unnamed: C25.2, R19.1
unnamed: J9.1, U1.3 (LOUT-)
unnamed: J9.2, U1.1 (LOUT+)
unnamed: J10.1, U1.14 (ROUT-)
unnamed: J10.2, U1.16 (ROUT+)
unnamed: J11.1, U2.3 (LOUT-)
unnamed: J11.2, U2.1 (LOUT+)
unnamed: J12.1, U2.14 (ROUT-)
unnamed: J12.2, U2.16 (ROUT+)
unnamed: C8.2, U1.8 (VREF)
unnamed: C19.2, U2.8 (VREF)
PAM_SHDN: R8.1, R13.1, U1.12 (~SHDN), U2.12 (~SHDN); also elsewhere on the board

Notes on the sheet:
place: 1uF at PVDD-4 1uF at PVDD-13 1uF at VDD-6

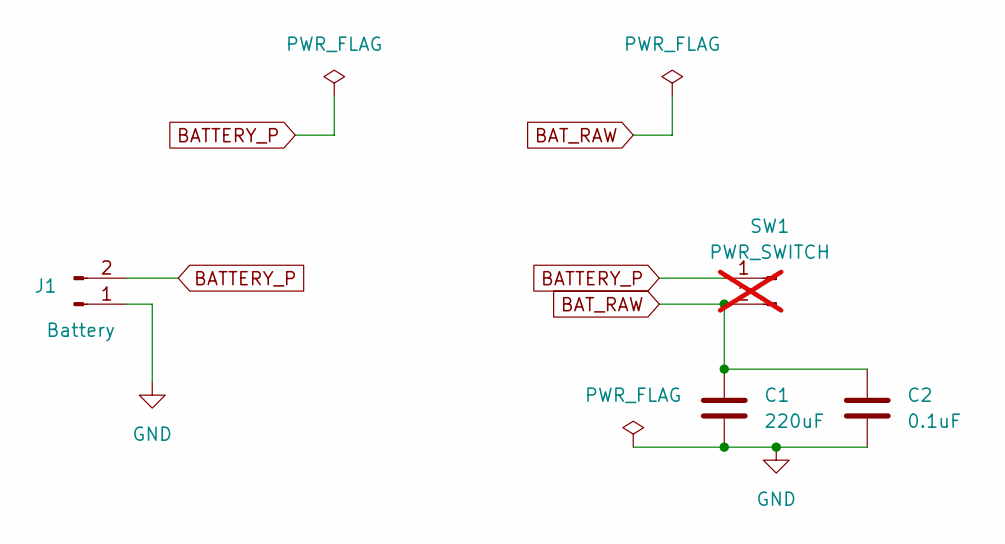
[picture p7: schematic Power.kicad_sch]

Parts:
C1: 220uF; CP_Elec_6.3x5.4
C2: 0.1uF; C_0805_2012Metric
J1: Battery; JST_PH_S2B-PH-K_1x02_P2.00mm_Horizontal
SW1: PWR_SWITCH; SolderWire-0.5sqmm_1x02_P4.6mm_D0.9mm_OD2.1mm; not fitted

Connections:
BATTERY_P: J1.2, SW1.1
BAT_RAW: C1.1, C2.1, SW1.2; also elsewhere on the board
GND: C1.2, C2.2, J1.1; also elsewhere on the board

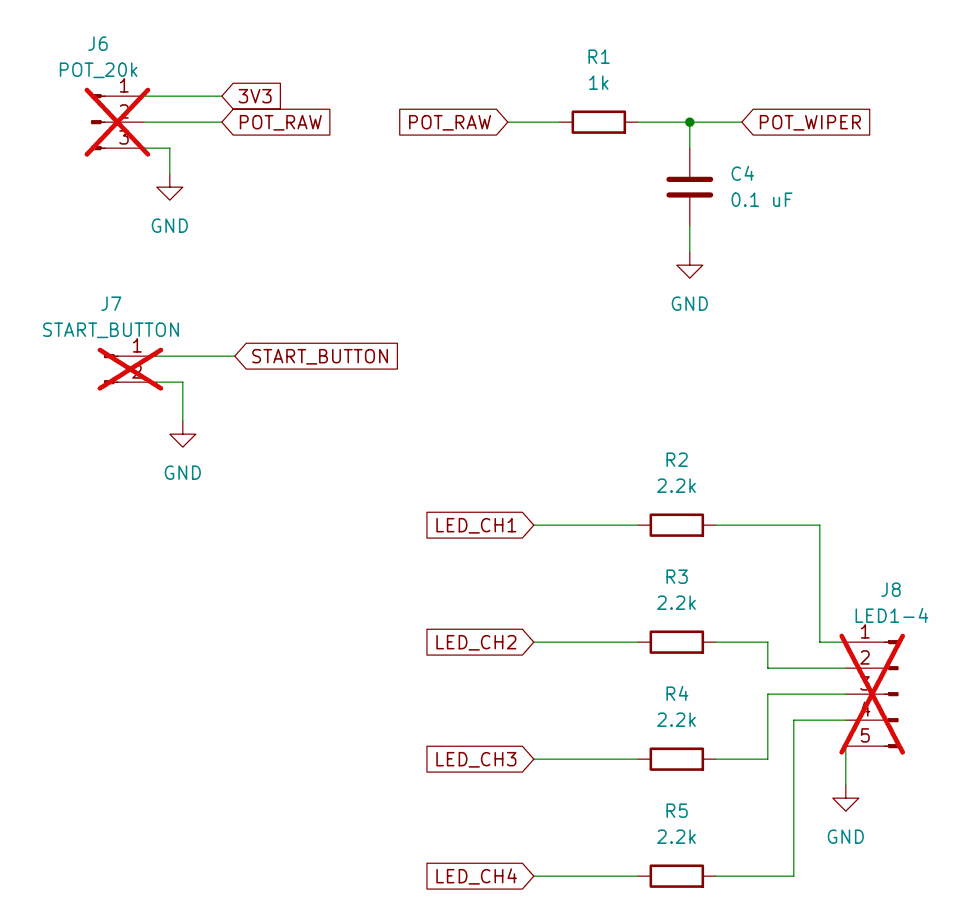
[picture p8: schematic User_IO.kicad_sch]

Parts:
C4: 0.1 uF; C_0805_2012Metric
J6: POT_20k; SolderWire-0.5sqmm_1x03_P4.6mm_D0.9mm_OD2.1mm; not fitted
J7: START_BUTTON; SolderWire-0.5sqmm_1x02_P4.6mm_D0.9mm_OD2.1mm; not fitted
J8: LED1-4; PinHeader_1x05_P2.54mm_Vertical; not fitted
R1: 1k; R_0805_2012Metric
R2, R3, R4, R5: 2.2k; R_0805_2012Metric

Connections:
3V3: J6.1; also elsewhere on the board
GND: C4.2, J6.3, J7.2, J8.5; also elsewhere on the board
LED_CH1: R2.1; also elsewhere on the board
LED_CH2: R3.1; also elsewhere on the board
LED_CH3: R4.1; also elsewhere on the board
LED_CH4: R5.1; also elsewhere on the board
unnamed: J8.1, R2.2
unnamed: J8.2, R3.2
unnamed: J8.3, R4.2
unnamed: J8.4, R5.2
POT_RAW: J6.2, R1.1
POT_WIPER: C4.1, R1.2; also elsewhere on the board
START_BUTTON: J7.1; also elsewhere on the board

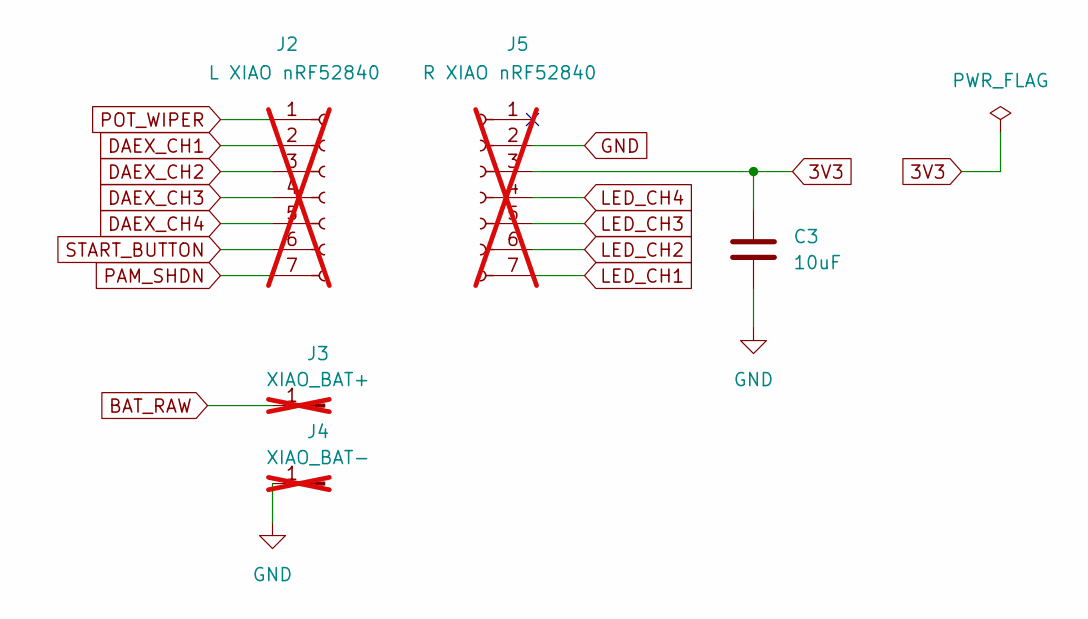
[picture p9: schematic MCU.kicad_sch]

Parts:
C3: 10uF; C_0805_2012Metric
J2: L XIAO nRF52840; PinHeader_1x07_P2.54mm_Vertical; not fitted
J3: XIAO_BAT+; SolderWire-0.5sqmm_1x01_D0.9mm_OD2.1mm; not fitted
J4: XIAO_BAT-; SolderWire-0.5sqmm_1x01_D0.9mm_OD2.1mm; not fitted
J5: R XIAO nRF52840; PinHeader_1x07_P2.54mm_Vertical; not fitted

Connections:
3V3: C3.1, J5.3; also elsewhere on the board
BAT_RAW: J3.1; also elsewhere on the board
DAEX_CH1: J2.2; also elsewhere on the board
DAEX_CH2: J2.3; also elsewhere on the board
DAEX_CH3: J2.4; also elsewhere on the board
DAEX_CH4: J2.5; also elsewhere on the board
GND: C3.2, J4.1, J5.2; also elsewhere on the board
LED_CH1: J5.7; also elsewhere on the board
LED_CH2: J5.6; also elsewhere on the board
LED_CH3: J5.5; also elsewhere on the board
LED_CH4: J5.4; also elsewhere on the board
PAM_SHDN: J2.7; also elsewhere on the board
POT_WIPER: J2.1; also elsewhere on the board
START_BUTTON: J2.6; also elsewhere on the board

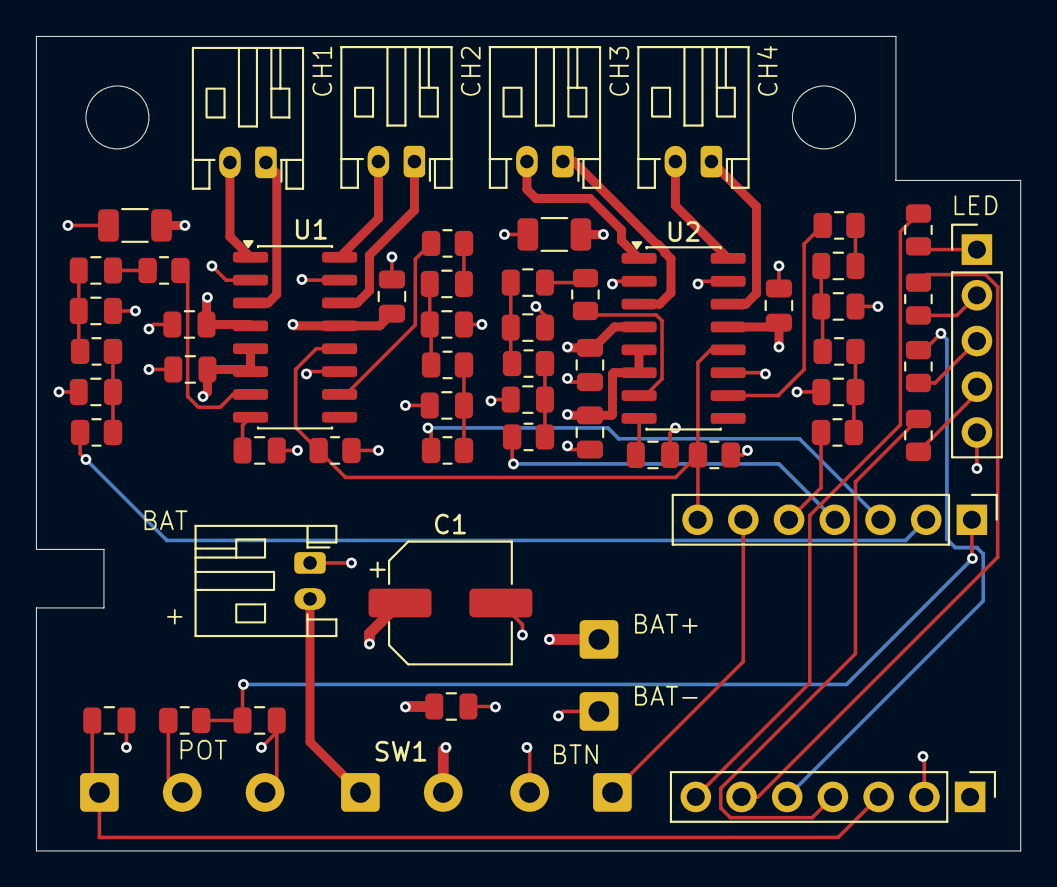
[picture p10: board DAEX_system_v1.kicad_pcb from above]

Board: 4 copper layers, 54.7 x 45.2 mm, 62 parts (0 on the bottom side), 46 nets.

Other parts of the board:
H1, H2: MountingHole_3.5mm

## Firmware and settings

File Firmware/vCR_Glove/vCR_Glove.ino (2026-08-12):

#include <bluefruit.h>
#include <math.h>
#include <nrf.h>

// ============================================================================
// DAEX_PAM8403_BLE_Tass_3to2_sinePWM_v6_double_shuffle
//
// Structural base:
//   DAEX_PAM8403_BLE_Tass_3to2_v1
//
// Signal-generation change:
//   Replaces the former 250 Hz narrow-pulse drive with a continuously running
//   64 kHz PWM/EasyDMA waveform. During a 100 ms burst, one channel's PWM duty
//   is sinusoidally modulated at the selected vibration frequency. All inactive channels remain at 50%
//   PWM duty, so every PAM8403 input has the carrier and only the selected
//   channel has the 250 Hz modulation.
//
// Existing PCB use before RC filters:
//   Scope each PAM input. The selected channel should show 64 kHz PWM with a
//   selected-frequency duty envelope for 100 ms. The other three inputs should show steady
//   50% PWM carrier.
// ============================================================================
//
// v6 changes:
//   1. Retains selectable single-frequency or four-frequency stimulation.
//   2. Single-frequency mode drives every burst at 250 Hz.
//   3. Multi-frequency mode now uses an independent "double shuffle":
//        - one random permutation chooses the four finger/channel locations;
//        - a second independent random permutation chooses the four frequencies.
//      Each 4-burst CR cycle therefore uses every finger once and every
//      frequency once, with no fixed finger-to-frequency association.
//   4. The multi-frequency set is:
//        207.65 Hz, 233.08 Hz, 277.18 Hz, 311.13 Hz.
//   5. Immediate repeats across permutation boundaries are prevented
//      independently for both finger order and frequency order.
//   6. Uses one nRF52840 hardware PWM peripheral per physical DAEX channel.
//      In multi-frequency mode an inactive channel is reconfigured just before
//      its burst for the frequency assigned by the frequency shuffle.
//   7. BLE START/READY/GO synchronization and the Tass 3:2 timing are unchanged.
//   8. MULTI_FREQUENCY_MODE is an experimental deviation from the
//      single-frequency Tass-style stimulation protocol; it has not been
//      clinically validated by this project.
//   9. LED_ENABLE may suppress burst-indicator flashing.
// ============================================================================

// ============================================================================
// USER CONFIGURATION
// Edit this section for normal setup changes. Values are arranged roughly from
// most likely to least likely to be changed by the user.
// ============================================================================

// ---------------- Hand identity ----------------
// 0 = right-hand unit
// 1 = left-hand unit
//
// The left-hand PCB connectors are physically ordered LRMI, so left-hand
// firmware always reverses the physical channel index. Logical channels 0..3
// therefore correspond to anatomical fingers IMRL on both hands.
#define IS_LEFT_HAND 0

// ---------------- Bilateral operation ----------------
// true  = both hands use the same shuffle sequence, so corresponding fingers
//         receive simultaneous bursts.
// false = both hands remain synchronized in time, but the left hand uses an
//         independent shuffle sequence. Finger selections between hands are
//         independent but simultaneous.
//
// This setting changes only the shuffle sequence. It does not alter the common
// jitter sequence or synchronized event timing.
const bool BILATERAL_MIRROR = true;

// ---------------- Stimulation protocol ----------------
// false = every burst uses SINGLE_FREQUENCY_HZ.
// true  = each 4-burst CR cycle independently shuffles both:
//         (1) the four logical finger channels and
//         (2) the four frequencies in MULTI_FREQUENCY_HZ[].
//         There is therefore no fixed finger-to-frequency assignment.
//
// IMPORTANT: MULTI_FREQUENCY_MODE is an experimental project option and is a
// significant deviation from the single-frequency Tass-style vCR protocol.
const bool MULTI_FREQUENCY_MODE = true;

const float SINGLE_FREQUENCY_HZ = 250.0f;  // allowed range: 60 to 350 Hz

const float MULTI_FREQUENCY_HZ[4] = {
  207.65f,  // G# below middle C
  233.08f,  // A# / Bb
  277.18f,  // C# / Db
  311.13f   // D# / Eb
};

const unsigned long PULSE_TIME_MS = 100;
const unsigned long DELAY_TIME_0_MS = 67;
const uint8_t ACTIVE_CR_COUNT = 3;
const uint8_t REST_CR_COUNT = 2;

// ---------------- Vibration amplitude ----------------
// Potentiometer endpoints map to these PWM sine-amplitude counts.
static constexpr int16_t MIN_AMPLITUDE_COUNTS = 2;
static constexpr int16_t MAX_AMPLITUDE_COUNTS = 50;

// ---------------- Jitter ----------------
// Set to 0.0f for no jitter. Tass noisy example: 0.235f.
const float JITTER_FRACTION = 0.235f;

// ---------------- BLE timing ----------------
const unsigned long SCAN_TIMEOUT_MS = 5000;
const unsigned long SYNC_DELAY_MS = 700;
const unsigned long ACK_TIMEOUT_MS = 250;
const uint8_t MAX_START_ATTEMPTS = 3;

// ---------------- Indicators ----------------
const bool LED_ENABLE = true;
const unsigned long LED_ON_TIME_MS = 100;

// ---------------- Deterministic random seeds ----------------
// The right hand always uses SHUFFLE_SEED_DEFAULT.
// In bilateral mirror mode, the left hand uses the same seed.
// In independent mode, the left hand uses SHUFFLE_SEED_INDEPENDENT.
const uint32_t SHUFFLE_SEED_DEFAULT = 123456UL;
const uint32_t SHUFFLE_SEED_INDEPENDENT = 654321UL;

// Frequency order uses a separate random stream so the frequency permutation is
// independent of the finger/channel permutation. Mirror mode uses the same
// frequency seed on both hands; independent bilateral mode uses a different
// left-hand seed.
const uint32_t FREQUENCY_SEED_DEFAULT = 314159UL;
const uint32_t FREQUENCY_SEED_INDEPENDENT = 271828UL;

// Jitter uses a separate common random stream, so changing shuffle correlation
// does not change jitter values or synchronized timing between hands.
const uint32_t COMMON_JITTER_SEED = 24681357UL;

// ============================================================================
// HARDWARE AND DERIVED CONSTANTS
// Normally do not edit below this line for routine configuration changes.
// ============================================================================

static constexpr uint8_t N_CH = 4;

// ---------------- Arduino pin assignments from the existing PCB ----------------
#define PIN_POT       A0
#define PIN_DAEX1     D1
#define PIN_DAEX2     D2
#define PIN_DAEX3     D3
#define PIN_DAEX4     D4
#define PIN_BUTTON    D5

#define PIN_LED1      D7
#define PIN_LED2      D8
#define PIN_LED3      D9
#define PIN_LED4      D10

#define PIN_PAM_SHDN  D6

// Direct nRF52840 GPIO numbers corresponding to XIAO silk D1-D4.
// PSEL uses 0..31 for Port 0 and 32..47 for Port 1.
static constexpr uint32_t DAEX_NRF_PSEL[N_CH] = {
  3,   // D1 = P0.03
  28,  // D2 = P0.28
  29,  // D3 = P0.29
  4    // D4 = P0.04
};

// ---------------- BLE ----------------
BLEUart bleuart;
BLEClientUart clientUart;

bool running = false;
bool startScheduled = false;
unsigned long startAtMs = 0;

bool lastButton = HIGH;
unsigned long lastDebounceMs = 0;

bool lookingForPeer = false;
unsigned long scanStartMs = 0;

bool awaitingReadyAck = false;
unsigned long readyWaitStartMs = 0;
uint8_t startRequestAttempts = 0;
uint16_t activeCentralConnHandle = 0xFFFFU;

// ---------------- Derived stimulation timing ----------------
const unsigned long PULSE_TIME_US = PULSE_TIME_MS * 1000UL;
const unsigned long DELAY_TIME_0_US = DELAY_TIME_0_MS * 1000UL;

const unsigned long CR_PERIOD_MS =
    N_CH * (PULSE_TIME_MS + DELAY_TIME_0_MS);          // 668 ms
const unsigned long CR_PERIOD_US = CR_PERIOD_MS * 1000UL;

const unsigned long REST_TIME_0_MS =
    REST_CR_COUNT * CR_PERIOD_MS;                      // 1336 ms
const unsigned long REST_TIME_0_US = REST_TIME_0_MS * 1000UL;

const int daexPhysicalPins[N_CH] = {
  PIN_DAEX1, PIN_DAEX2, PIN_DAEX3, PIN_DAEX4
};

const int ledPhysicalPins[N_CH] = {
  PIN_LED1, PIN_LED2, PIN_LED3, PIN_LED4
};

uint8_t channelOrder[N_CH];
uint8_t frequencyOrder[N_CH];

int8_t previousChannel = -1;
int8_t previousFrequencyIndex = -1;
uint32_t nextEventUs = 0;

// Separate deterministic random states for finger shuffle, frequency shuffle,
// and jitter.
uint32_t shuffleRngState = 1;
uint32_t frequencyRngState = 1;
uint32_t jitterRngState = 1;

// ---------------- PWM/EasyDMA sine generation ----------------
// Keep the tested PWM carrier fixed at 64 kHz so the existing two-pole RC
// reconstruction filters retain the same carrier rejection.
static constexpr uint32_t PWM_CLOCK_HZ = 16000000UL;
static constexpr uint32_t PWM_CARRIER_HZ = 64000UL;
static constexpr uint16_t PWM_TOP = PWM_CLOCK_HZ / PWM_CARRIER_HZ;  // 250
static constexpr uint16_t PWM_CENTER = PWM_TOP / 2U;                // 125

// Each physical DAEX channel uses its own nRF52840 PWM peripheral. This lets
// each channel have a different vibration frequency without changing protocol
// timing or interrupting the other channels' 64 kHz carriers.
NRF_PWM_Type * const PWM_INSTANCE[N_CH] = {
  NRF_PWM0,
  NRF_PWM1,
  NRF_PWM2,
  NRF_PWM3
};

// At startup, choose SINE_SAMPLES = 32..128 and
// R = PWM_REFRESH + 1 = 2..10 independently for each physical channel:
//
//   actual frequency = PWM_CARRIER_HZ / (SINE_SAMPLES * R)
//
// For requested frequencies from 60 to 300 Hz, this search normally gives an
// exact result or an error below about 0.6%.
static constexpr uint16_t MIN_SINE_SAMPLES = 32;
static constexpr uint16_t MAX_SINE_SAMPLES = 128;
static constexpr uint16_t MIN_SAMPLE_HOLD_R = 2;
static constexpr uint16_t MAX_SAMPLE_HOLD_R = 10;
static constexpr float MIN_VIBRATION_FREQUENCY_HZ = 60.0f;
static constexpr float MAX_VIBRATION_FREQUENCY_HZ = 350.0f;

struct PwmTiming {
  uint16_t sineSamples;
  uint16_t sampleHoldR;
  uint16_t pwmRefresh;
  float requestedFrequencyHz;
  float actualFrequencyHz;
};

PwmTiming pwmTimingPhysical[N_CH];
// Pot is sampled once at the start of each burst.
static constexpr uint16_t ADC_MAX = 4095;
static constexpr uint8_t POT_AVERAGE_SAMPLES = 8;

// Each PWM peripheral uses LOAD=Common and therefore needs one halfword per
// waveform step. A separate EasyDMA buffer is maintained for each physical
// DAEX channel.
static uint16_t pwmSequence[N_CH][MAX_SINE_SAMPLES]
    __attribute__((aligned(4)));

// ---------------- Utility ----------------
uint8_t physicalIndexForLogical(uint8_t logicalChannel) {
  // Physical connector order is IMRL on the right hand and LRMI on the left.
  // Reverse the left-hand physical index so logical channels 0..3 correspond
  // to anatomical fingers IMRL on both hands in both bilateral modes.
#if IS_LEFT_HAND
  return (N_CH - 1U) - logicalChannel;
#else
  return logicalChannel;
#endif
}

int ledPinForLogical(uint8_t logicalChannel) {
  return ledPhysicalPins[physicalIndexForLogical(logicalChannel)];
}

void allLedsOff() {
  for (uint8_t i = 0; i < N_CH; i++) {
    digitalWrite(ledPhysicalPins[i], LOW);
  }
}

uint16_t readPotentiometer() {
  uint32_t sum = 0;

  for (uint8_t i = 0; i < POT_AVERAGE_SAMPLES; i++) {
    sum += analogRead(PIN_POT);
  }

  return (uint16_t)(sum / POT_AVERAGE_SAMPLES);
}

int16_t potToAmplitude(uint16_t potReading) {
  if (potReading > ADC_MAX) potReading = ADC_MAX;

  const uint32_t amplitudeRange =
      (uint32_t)(MAX_AMPLITUDE_COUNTS - MIN_AMPLITUDE_COUNTS);

  const uint32_t scaled =
      (uint32_t)potReading * amplitudeRange;

  return (int16_t)(MIN_AMPLITUDE_COUNTS +
      ((scaled + ADC_MAX / 2U) / ADC_MAX));
}

void waitUntilUs(uint32_t targetUs) {
  while ((int32_t)(micros() - targetUs) < 0) {
    int32_t remainingUs = (int32_t)(targetUs - micros());

    if (remainingUs > 2000) {
      delay(1);
    } else if (remainingUs > 50) {
      delayMicroseconds((unsigned int)(remainingUs - 25));
    }
  }
}

void scheduleStart() {
  if (running || startScheduled) return;
  startAtMs = millis() + SYNC_DELAY_MS;
  startScheduled = true;
}

void stopBleActivity() {
  Bluefruit.Scanner.stop();
  Bluefruit.Advertising.restartOnDisconnect(false);
  Bluefruit.Advertising.stop();
  lookingForPeer = false;
}

uint32_t nextRandom32(uint32_t &state) {
  // xorshift32 cannot use a zero state.
  if (state == 0U) state = 0x6D2B79F5UL;

  uint32_t x = state;
  x ^= x << 13;
  x ^= x >> 17;
  x ^= x << 5;
  state = x;
  return x;
}

uint32_t randomBelow(uint32_t &state, uint32_t upperExclusive) {
  if (upperExclusive == 0U) return 0U;
  return nextRandom32(state) % upperExclusive;
}

int32_t randomInclusive(
    uint32_t &state,
    int32_t lowerInclusive,
    int32_t upperInclusive) {
  if (upperInclusive <= lowerInclusive) return lowerInclusive;

  const uint32_t span =
      (uint32_t)((int64_t)upperInclusive - (int64_t)lowerInclusive + 1LL);

  return lowerInclusive +
      (int32_t)(nextRandom32(state) % span);
}

uint32_t selectedShuffleSeed() {
#if IS_LEFT_HAND
  // The left hand shares the default seed in mirror mode and uses a different
  // seed in non-mirror mode. Physical channel reversal is handled separately
  // by physicalIndexForLogical().
  return BILATERAL_MIRROR
      ? SHUFFLE_SEED_DEFAULT
      : SHUFFLE_SEED_INDEPENDENT;
#else
  // The right hand always uses the default seed.
  return SHUFFLE_SEED_DEFAULT;
#endif
}

uint32_t selectedFrequencySeed() {
#if IS_LEFT_HAND
  return BILATERAL_MIRROR
      ? FREQUENCY_SEED_DEFAULT
      : FREQUENCY_SEED_INDEPENDENT;
#else
  return FREQUENCY_SEED_DEFAULT;
#endif
}

void resetRandomSequence() {
  shuffleRngState = selectedShuffleSeed();
  frequencyRngState = selectedFrequencySeed();
  jitterRngState = COMMON_JITTER_SEED;

  for (uint8_t i = 0; i < N_CH; i++) {
    channelOrder[i] = i;
    frequencyOrder[i] = i;
  }

  previousChannel = -1;
  previousFrequencyIndex = -1;
}

void shuffleChannels() {
  for (int i = N_CH - 1; i > 0; i--) {
    int j = (int)randomBelow(shuffleRngState, (uint32_t)(i + 1));

    uint8_t temp = channelOrder[i];
    channelOrder[i] = channelOrder[j];
    channelOrder[j] = temp;
  }

  if (previousChannel >= 0 && channelOrder[0] == previousChannel) {
    uint8_t temp = channelOrder[0];
    channelOrder[0] = channelOrder[1];
    channelOrder[1] = temp;
  }
}

void shuffleFrequencies() {
  for (int i = N_CH - 1; i > 0; i--) {
    int j = (int)randomBelow(frequencyRngState, (uint32_t)(i + 1));

    uint8_t temp = frequencyOrder[i];
    frequencyOrder[i] = frequencyOrder[j];
    frequencyOrder[j] = temp;
  }

  if (previousFrequencyIndex >= 0 &&
      frequencyOrder[0] == previousFrequencyIndex) {
    uint8_t temp = frequencyOrder[0];
    frequencyOrder[0] = frequencyOrder[1];
    frequencyOrder[1] = temp;
  }
}

int32_t makeDelayJitterUs() {
  if (JITTER_FRACTION <= 0.0f) return 0;

  float requestedLimitUs =
      JITTER_FRACTION * ((float)CR_PERIOD_US / (2.0f * (float)N_CH));

  int32_t limitUs = (int32_t)(requestedLimitUs + 0.5f);
  if (limitUs < 1) return 0;

  return randomInclusive(jitterRngState, -limitUs, limitUs);
}

// Return the requested vibration frequency for one frequency-list index.
// In single-frequency mode the index is ignored.
float requestedFrequencyForIndex(uint8_t frequencyIndex) {
  if (!MULTI_FREQUENCY_MODE) {
    return SINGLE_FREQUENCY_HZ;
  }

  if (frequencyIndex >= N_CH) frequencyIndex = 0;
  return MULTI_FREQUENCY_HZ[frequencyIndex];
}

// Select the sine-table length and sample-hold count that produce the closest
// available vibration frequency while keeping the 64 kHz carrier fixed.
PwmTiming choosePwmTiming(float requestedHz) {
  float targetHz = requestedHz;

  if (targetHz < MIN_VIBRATION_FREQUENCY_HZ) {
    targetHz = MIN_VIBRATION_FREQUENCY_HZ;
  } else if (targetHz > MAX_VIBRATION_FREQUENCY_HZ) {
    targetHz = MAX_VIBRATION_FREQUENCY_HZ;
  }

  float bestErrorHz = 1.0e9f;
  uint16_t bestN = MIN_SINE_SAMPLES;
  uint16_t bestR = MIN_SAMPLE_HOLD_R;
  float bestActualHz = 0.0f;
  const float tieToleranceHz = 0.0001f;

  for (uint16_t n = MIN_SINE_SAMPLES; n <= MAX_SINE_SAMPLES; n++) {
    for (uint16_t r = MIN_SAMPLE_HOLD_R; r <= MAX_SAMPLE_HOLD_R; r++) {
      const float actualHz =
          (float)PWM_CARRIER_HZ / ((float)n * (float)r);
      const float errorHz = fabsf(actualHz - targetHz);

      if (errorHz < bestErrorHz - tieToleranceHz ||
          (fabsf(errorHz - bestErrorHz) <= tieToleranceHz && n > bestN)) {
        bestErrorHz = errorHz;
        bestN = n;
        bestR = r;
        bestActualHz = actualHz;
      }
    }
  }

  PwmTiming result;
  result.sineSamples = bestN;
  result.sampleHoldR = bestR;
  result.pwmRefresh = bestR - 1U;
  result.requestedFrequencyHz = requestedHz;
  result.actualFrequencyHz = bestActualHz;
  return result;
}

// Initialize every physical PWM output with the single-frequency timing.
// In multi-frequency mode, each inactive physical channel is reconfigured at
// burst time for the independently shuffled frequency assigned to that burst.
void selectAllPwmTimings() {
  Serial.println();
  Serial.print("Frequency mode: ");
  Serial.println(MULTI_FREQUENCY_MODE ? "MULTI - DOUBLE SHUFFLE" : "SINGLE");

  const PwmTiming initialTiming =
      choosePwmTiming(SINGLE_FREQUENCY_HZ);

  for (uint8_t physicalChannel = 0;
       physicalChannel < N_CH;
       physicalChannel++) {
    pwmTimingPhysical[physicalChannel] = initialTiming;
  }

  if (!MULTI_FREQUENCY_MODE) {
    Serial.print("  Requested ");
    Serial.print(initialTiming.requestedFrequencyHz, 3);
    Serial.print(" Hz, actual ");
    Serial.print(initialTiming.actualFrequencyHz, 3);
    Serial.print(" Hz, error ");
    Serial.print(
        initialTiming.actualFrequencyHz -
        initialTiming.requestedFrequencyHz,
        3);
    Serial.print(" Hz, N=");
    Serial.print(initialTiming.sineSamples);
    Serial.print(", R=");
    Serial.println(initialTiming.sampleHoldR);
    return;
  }

  Serial.println("  Available shuffled frequencies:");
  for (uint8_t frequencyIndex = 0;
       frequencyIndex < N_CH;
       frequencyIndex++) {
    const PwmTiming timing =
        choosePwmTiming(MULTI_FREQUENCY_HZ[frequencyIndex]);

    Serial.print("    F");
    Serial.print(frequencyIndex);
    Serial.print(": requested ");
    Serial.print(timing.requestedFrequencyHz, 3);
    Serial.print(" Hz, actual ");
    Serial.print(timing.actualFrequencyHz, 3);
    Serial.print(" Hz, error ");
    Serial.print(
        timing.actualFrequencyHz - timing.requestedFrequencyHz,
        3);
    Serial.print(" Hz, N=");
    Serial.print(timing.sineSamples);
    Serial.print(", R=");
    Serial.println(timing.sampleHoldR);
  }
}

// ---------------- PWM table construction ----------------
void buildQuietSequencePhysical(uint8_t physicalChannel) {
  const uint16_t n =
      pwmTimingPhysical[physicalChannel].sineSamples;

  for (uint16_t sample = 0; sample < n; sample++) {
    pwmSequence[physicalChannel][sample] = PWM_CENTER;
  }
}

void buildAllQuietSequences() {
  for (uint8_t physicalChannel = 0;
       physicalChannel < N_CH;
       physicalChannel++) {
    buildQuietSequencePhysical(physicalChannel);
  }
}

void buildBurstSequence(uint8_t logicalChannel, int16_t amplitudeCounts) {
  const uint8_t activePhysicalChannel =
      physicalIndexForLogical(logicalChannel);

  const uint16_t n =
      pwmTimingPhysical[activePhysicalChannel].sineSamples;

  for (uint16_t sample = 0; sample < n; sample++) {
    const float phase =
        2.0f * PI * (float)sample / (float)n;

    int32_t compareValue =
        (int32_t)PWM_CENTER +
        (int32_t)lroundf((float)amplitudeCounts * sinf(phase));

    if (compareValue < 0) compareValue = 0;
    if (compareValue > PWM_TOP) compareValue = PWM_TOP;

    pwmSequence[activePhysicalChannel][sample] =
        (uint16_t)compareValue;
  }
}
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
void loop() {
  if (!running) {
    checkIncomingUart();
    checkIncomingClientUart();
    serviceReadyTimeout();
    checkButton();

    if (lookingForPeer && (millis() - scanStartMs > SCAN_TIMEOUT_MS)) {
      // No usable peer handshake was completed. Stop all BLE activity and
      // commit to local-only operation. A late peer cannot join this session;
      // both units must be power-cycled to restore bilateral synchronization.
      stopBleActivity();
      awaitingReadyAck = false;

      if (activeCentralConnHandle != 0xFFFFU) {
        Bluefruit.disconnect(activeCentralConnHandle);
      }

      scheduleStart();
    }
  }

  updateHaptics();
}

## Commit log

2026-08-11 Add KiCad source and JLCPCB production files
    [DAEX_system_v1.kicad_pcb, DAEX_system_v1.kicad_sch, DAEX_system_v1_BOM.csv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]
2026-08-11 Reorganize 3D files by component and manufacturing process
    [DAEX_assembly.scad, DAEX_dimensions.scad, DAEX_lower_plate.scad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]
2026-08-12 loaded files into the repository
    [vCR_glove_enclosure.scad, vCR_glove_enclosure_bottom.stl, vCR_glove_enclosure_top.stl]
2026-08-12 Corrected version and upgraded with multi-frequency option
    [vCR_Glove.ino]
2026-08-18 updated dimensions, features and versions
    [DAEX_assembly.scad, DAEX_dimensions.scad, DAEX_lower_plate.scad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]
2026-08-18 updated stl files and names
    [DAEX_lower_plate.stl, DAEX_lower_plate_v6.stl, DAEX_tapper.stl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]
2026-08-18 updated dims and version
    [vCR_glove_enclosure.scad, vCR_glove_enclosure_bottom.stl, vCR_glove_enclosure_top.stl]
